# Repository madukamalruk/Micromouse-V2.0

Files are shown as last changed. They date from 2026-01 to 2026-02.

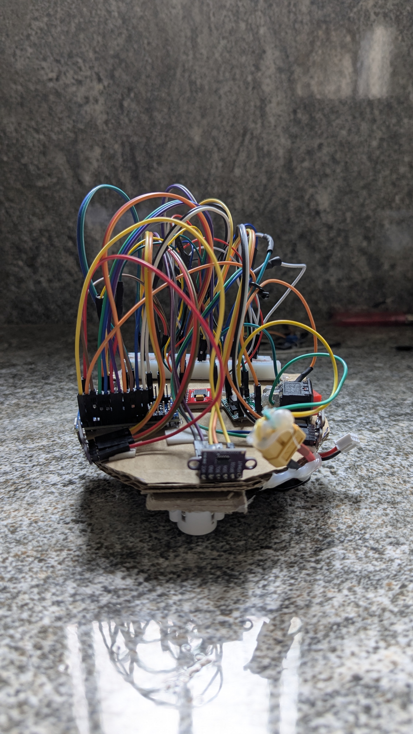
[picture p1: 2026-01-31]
IntialHardwareSetup/PXL_20260102_073045983.jpg

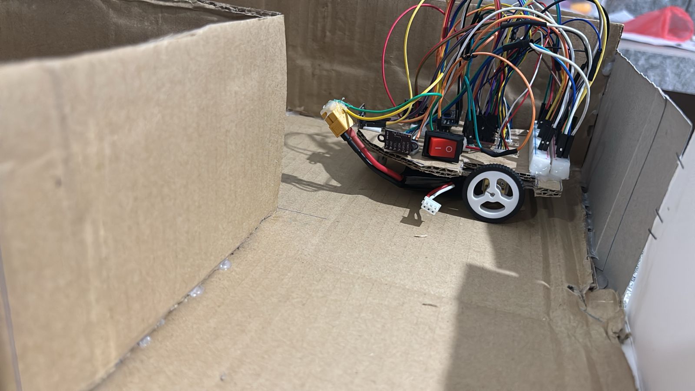
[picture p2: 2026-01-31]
IntialHardwareSetup/WhatsApp Image 2026-01-01 at 10.32.10 0PM.jpeg

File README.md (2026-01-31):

# 🐭 MazeMaster 2026 - Team MazeRiders





The official code repository for **Team MazeRiders**, a Top 5 Finalist at the **MazeMaster 2026** Micromouse competition organized by IEEE RAS Uva Wellassa University.

This project marks our transition from basic obstacle avoidance to an autonomous, intelligent maze-solving robot using the **Flood Fill Algorithm**.

---

## 🚀 Key Features

* **⚡ Autonomous Navigation:** Implements a full Flood Fill Algorithm to map and solve a 16x16 maze dynamically.
* **🧠 Two-Way Search Logic:** Features a robust "Start $\to$ Center $\to$ Start" verification run before committing the map to memory.
* **💾 Dual-Mode Operation:**
    * **Search Mode:** Explores the maze, updates wall data, and saves the verified map to EEPROM.
    * **Fast Run:** Loads the saved map and executes a high-speed run using a "Strict Visited Mask" for safety.
* **⚙️ Advanced Control System:**
    * **PID Wall Following:** Precision control using tuned $K_p$ and $K_d$ constants.
    * **Dual-Encoder Odometry:** Uses Hardware Interrupts and PCINT for precise distance tracking.
    * **Virtual Gyro:** Uses encoder differentials to maintain a straight heading in open spaces.

---

## 🛠️ Hardware Stack

| Component | Specification |
| :--- | :--- |
| **Microcontroller** | Arduino Nano (ATmega328P) |
| **Sensors** | 3x VL53L0X Time-of-Flight (ToF) Laser Sensors |
| **Motors** | N20 Gear Motors with Magnetic Encoders |
| **Driver** | TB6612FNG Dual Channel Motor Driver |
| **Power** | 2S LiPo (7.4V - 8.4V) |
| **Chassis** | Breadboard & 3D Printed Structural Components |

---

## 🏎️ How It Works

### 1. The Algorithm
The mouse treats the maze as a grid of values representing the distance to the center. We use the Flood Fill equation to update the "cost" of each cell:

$$Distance(cell) = 1 + \min(Neighbors)$$

### 2. Competition Strategy
1.  **Search Run:** The robot starts at (0,0), finds the center, and immediately drives back to the start to verify the path. The verified map is saved to non-volatile memory (**EEPROM**).
2.  **Fast Run:** The user flips a hardware switch. The robot loads the map and races to the center without scanning, strictly avoiding unvisited cells to prevent collisions.

---

## 📂 Project Structure

```bash
├── 📂Codes    # The final competition code 
├── 📂FinalHardware
├── 📂IntialHardwareSetup              
├── 📂Wiring+Dimensions                 
└── 📜 README.md   # Project documentation
```
## 👥 Team MazeRiders
• Maduka Malruk
• Sahas Wickramasinghe
• Sasidu Madhusankha

## 🏆 Achievements
• 4th Place - Round 1 (MazeMaster 2026)
• Top 4 Finalist - Final Round (MazeMaster 2026)
• Successfully implemented Flood Fill logic with custom PID tuning on an 8-bit microcontroller.

## 🤝 Acknowledgments
Special thanks to the IEEE RAS UWU Student Branch for organizing the event and the Micromouse community for the open-source knowledge that helped us migrate from Right-Hand Rule logic to Flood Fill.

### ⭐ Star this repo if you find our journey inspiring!

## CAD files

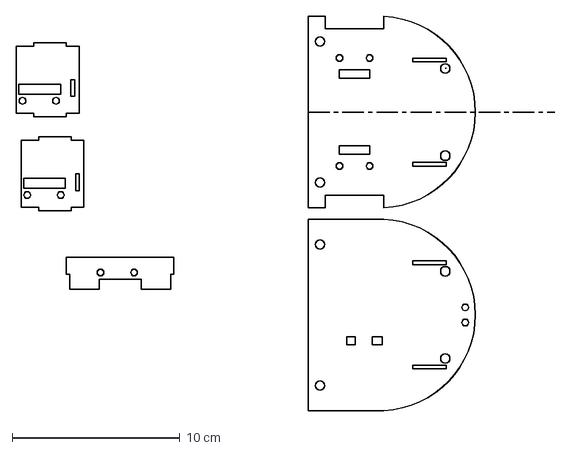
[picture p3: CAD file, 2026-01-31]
IntialHardwareSetup/board 3.DXF
32.1 x 23.5 cm

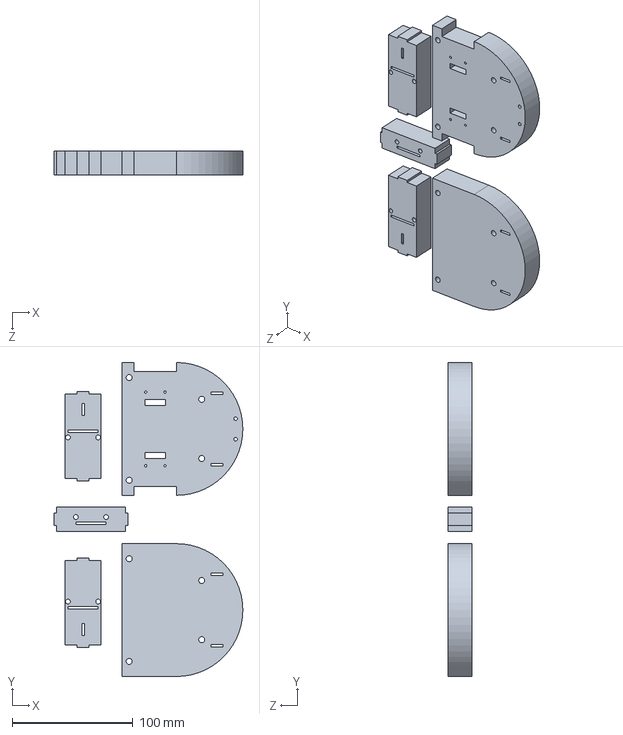
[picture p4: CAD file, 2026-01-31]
IntialHardwareSetup/board.SLDPRT
156.3 x 260.0 x 20.0 mm

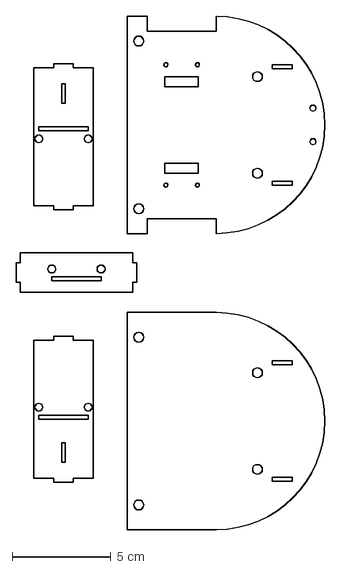
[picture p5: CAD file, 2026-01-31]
IntialHardwareSetup/board 1.DXF
15.6 x 26.0 cm

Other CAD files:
IntialHardwareSetup/board 2.SLDPRT
IntialHardwareSetup/Part1.SLDPRT
IntialHardwareSetup/board 2.DXF

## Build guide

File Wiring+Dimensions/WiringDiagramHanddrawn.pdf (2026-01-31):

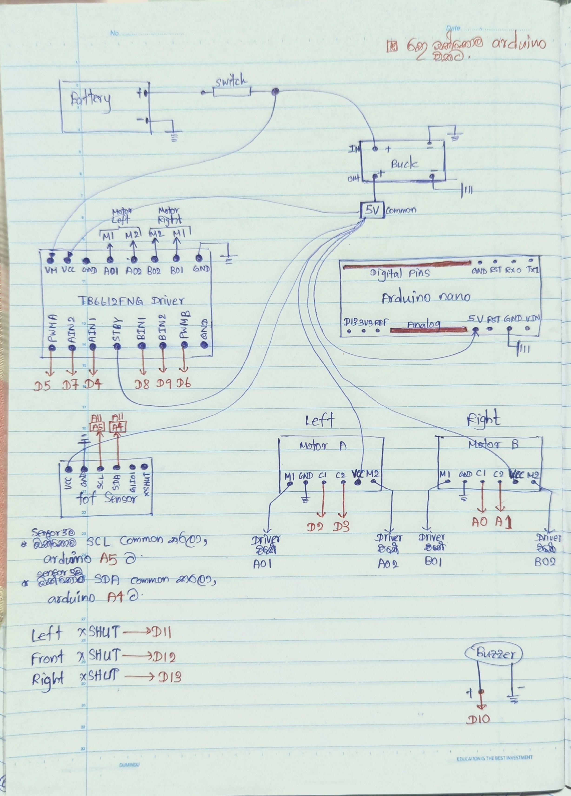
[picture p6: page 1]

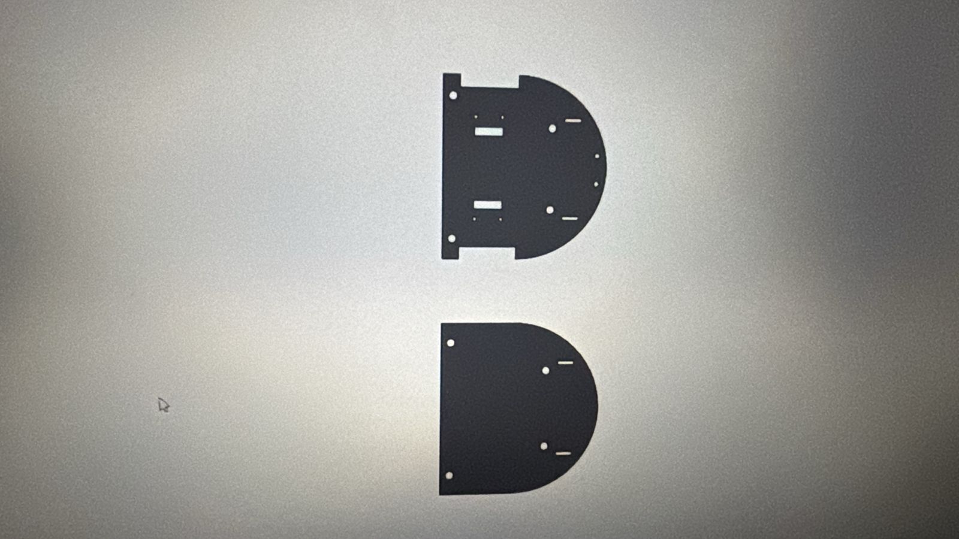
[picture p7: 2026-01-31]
IntialHardwareSetup/WhatsApp Image 2026-01-02 at 9.39.53 PM.jpeg

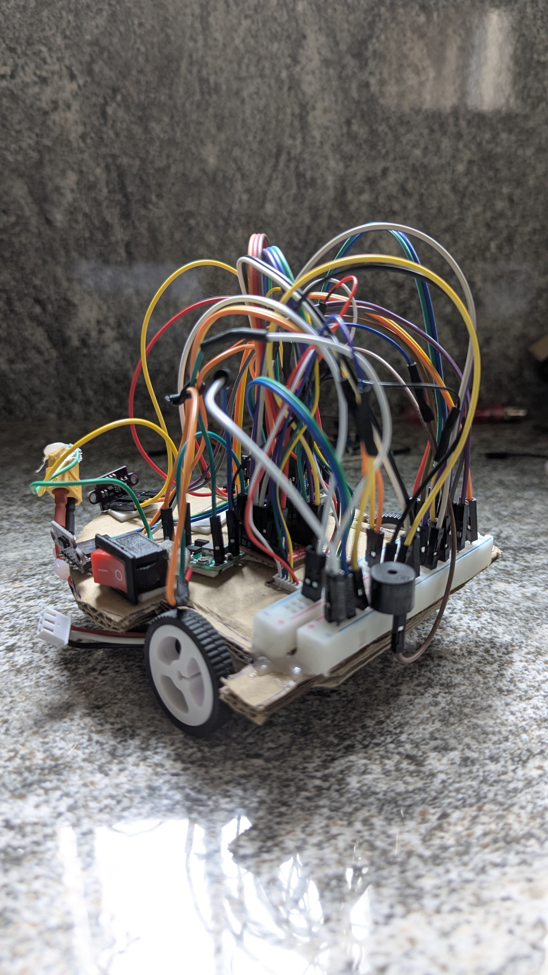
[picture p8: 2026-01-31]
IntialHardwareSetup/PXL_20260102_073117457.jpg

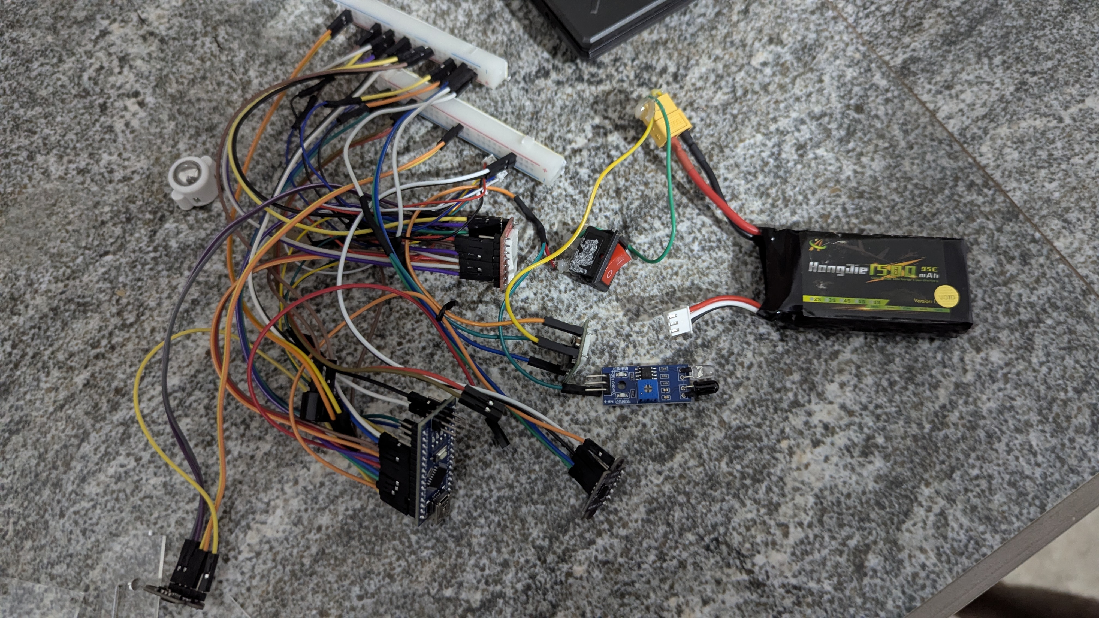
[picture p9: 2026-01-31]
IntialHardwareSetup/PXL_20260105_134254864.jpg

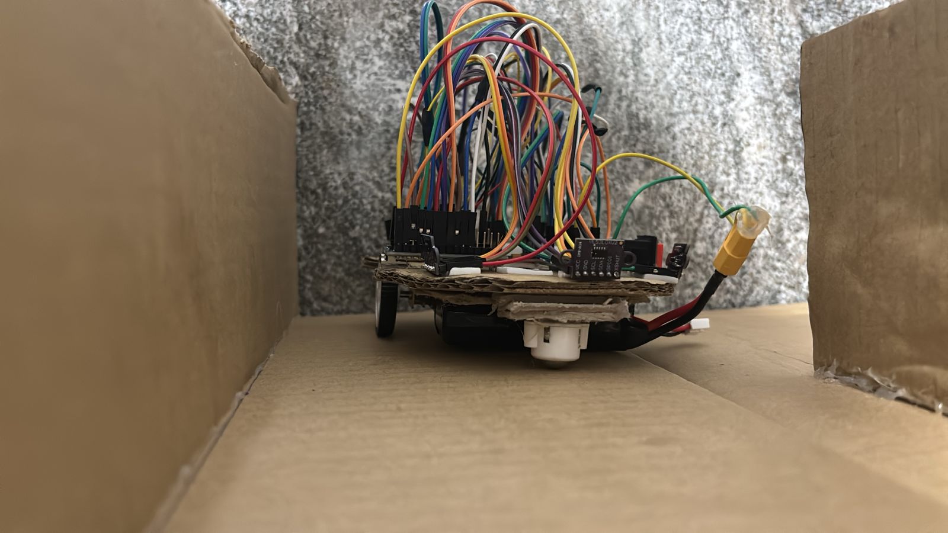
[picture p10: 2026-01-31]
IntialHardwareSetup/WhatsApp Image 2026-01-01 at 10.32.10 PM.jpeg

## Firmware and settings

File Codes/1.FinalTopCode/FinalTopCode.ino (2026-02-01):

#include <Wire.h>
#include <VL53L0X.h>
#include <EEPROM.h>

// *** TUNING MODE SELECTOR ***
// 0 = COMPETITION MODE (Standard Operation)
// 1 = TUNE DISTANCE (Moves 3 cells forward then stops)
// 2 = TUNE 90 TURN (Turns 90 degrees 4 times)
// 3 = TUNE 180 TURN (Turns 180 degrees 2 times)
const int TUNING_MODE = 2; 

// *** PHYSICAL CONSTANTS  ***
int TICKS_PER_CELL = 585;  
int TICKS_FOR_90   = 280;  
int TICKS_FOR_180  = 575; // Tune this using Mode 3!

// *** PID CONTROL ***
float Kp_Wall = 2.0;            
float Kd_Wall = 0.5;            
float Kp_Enc  = 1.0; 

// *** SPEED SETTINGS ***
int SEARCH_SPEED = 90;
int FAST_SPEED   = 100; 
int CURRENT_SPEED = 90; 
int WALL_DIST    = 75; 

// ================================================================
//               HARDWARE PIN DEFINITIONS
// ================================================================
const int AIN1 = 4; const int AIN2 = 7; const int PWMA = 5;
const int BIN1 = 9; const int BIN2 = 8; const int PWMB = 6;
const int ENCL_A = 2; const int ENCR_A = A0; 
const int buzzer = 10;
const int MODE_SWITCH_PIN = A3; 
const int xL = 11; const int xF = 12; const int xR = 13;

VL53L0X sensorL; VL53L0X sensorF; VL53L0X sensorR;

volatile long leftTicks = 0;
volatile long rightTicks = 0;

// Mapping
const int MAZE_SIZE = 16;
byte walls[16][16];       
byte dist[16][16];
byte visited[16][16]; 

int curX = 0; int curY = 0; int heading = 0;

enum RobotMode { IDLE, SEARCH_RUN, FAST_RUN };
RobotMode currentMode = IDLE;
bool searchingReturn = false; 

// ================================================================
//               INTERRUPTS
// ================================================================
void countLeft() { leftTicks++; }
ISR(PCINT1_vect) { if (digitalRead(ENCR_A) == HIGH) rightTicks++; }
long getAvgTicks() { noInterrupts(); long l = leftTicks; long r = rightTicks; interrupts(); return (l + r) / 2; }
void resetTicks() { noInterrupts(); leftTicks = 0; rightTicks = 0; interrupts(); }

// ================================================================
//               SETUP (Updated with Mode 3)
// ================================================================
void setup() {
  Serial.begin(9600);
  Wire.begin(); 

  pinMode(AIN1, OUTPUT); pinMode(AIN2, OUTPUT); pinMode(PWMA, OUTPUT);
  pinMode(BIN1, OUTPUT); pinMode(BIN2, OUTPUT); pinMode(PWMB, OUTPUT);
  pinMode(buzzer, OUTPUT); pinMode(MODE_SWITCH_PIN, INPUT_PULLUP);

  pinMode(ENCL_A, INPUT_PULLUP); attachInterrupt(digitalPinToInterrupt(ENCL_A), countLeft, RISING);
  pinMode(ENCR_A, INPUT_PULLUP); cli(); PCICR |= (1 << PCIE1); PCMSK1 |= (1 << PCINT8); sei();

  pinMode(xL, OUTPUT); pinMode(xF, OUTPUT); pinMode(xR, OUTPUT);
  digitalWrite(xL, LOW); digitalWrite(xF, LOW); digitalWrite(xR, LOW); delay(50);
  digitalWrite(xL, HIGH); delay(10); sensorL.init(); sensorL.setAddress(0x31); sensorL.setTimeout(500);
  digitalWrite(xF, HIGH); delay(10); sensorF.init(); sensorF.setAddress(0x30); sensorF.setTimeout(500);
  digitalWrite(xR, HIGH); delay(10); sensorR.init(); sensorR.setAddress(0x32); sensorR.setTimeout(500);
  sensorL.startContinuous(); sensorF.startContinuous(); sensorR.startContinuous();

  initMaze(); 
  searchingReturn = false; 

  // ============================================================
  //            TUNING MODES
  // ============================================================
  
  if (TUNING_MODE == 1) { 
    // *** MODE 1: DISTANCE TUNE ***
    // Move 3 cells forward
    for(int i=0; i<3; i++) { moveOneCell(); delay(500); } 
    while(1); 
  }
  else if (TUNING_MODE == 2) { 
    // *** MODE 2: 90 DEGREE TURN TUNE ***
    // Square path
    for(int i=0; i<4; i++) { turnInPlace(true, TICKS_FOR_90); delay(500); } 
    while(1); 
  }
  else if (TUNING_MODE == 3) {
    // *** MODE 3: 180 DEGREE U-TURN TUNE ***
    // Perform U-Turn, Wait, Perform U-Turn (Should be back at start heading)
    for(int i=0; i<2; i++) {
        turnInPlace(true, TICKS_FOR_180); 
        delay(1000);
    }
    while(1); // Freeze
  }
  else {
    // *** COMPETITION MODE ***
    if (digitalRead(MODE_SWITCH_PIN) == LOW) {
      currentMode = SEARCH_RUN;
      CURRENT_SPEED = SEARCH_SPEED;
      tone(buzzer, 1000, 200); delay(250); tone(buzzer, 1500, 400); 
    } else {
      currentMode = FAST_RUN;
      CURRENT_SPEED = FAST_SPEED;
      for(int i=0; i<3; i++) { tone(buzzer, 2000, 100); delay(150); }
      loadMapFromEEPROM();
      updateFlood();
    }
  }
  delay(1000); 
}

// ================================================================
//               MAIN LOOP
// ================================================================
void loop() {
  if (currentMode == SEARCH_RUN) runSearchLogic();
  else if (currentMode == FAST_RUN) runFastLogic();
}

// ================================================================
//               LOGIC: SEARCH RUN (Double-Save)
// ================================================================
void runSearchLogic() {
  visited[curX][curY] = 1;

  if (sensorF.readRangeContinuousMillimeters() < 150) setWall(curX, curY, heading);
  if (sensorR.readRangeContinuousMillimeters() < 150) setWall(curX, curY, (heading + 1) % 4);
  if (sensorL.readRangeContinuousMillimeters() < 150) setWall(curX, curY, (heading + 3) % 4);
  
  updateFlood(); 

  if (dist[curX][curY] == 0) {
    brake();
    
    if (!searchingReturn) {
        // Checkpoint Save (Center)
        saveMapToEEPROM(); 
        tone(buzzer, 2000, 100); delay(100); tone(buzzer, 2000, 100); delay(500);
        searchingReturn = true;
        updateFlood(); 
        return; 
    }
    else {
        // Final Save (Start)
        saveMapToEEPROM();
        tone(buzzer, 1000, 100); delay(150); tone(buzzer, 1500, 100); delay(150); tone(buzzer, 2000, 500);
        while(1); 
    }
  }
  
  int bestDir = -1;
  int minDist = 255;
  int checkOrder[4] = {0, 1, 3, 2}; 
  
  for(int i=0; i<4; i++) {
    int dir = (heading + checkOrder[i]) % 4;
    if (!isWall(curX, curY, dir)) {
      int nx = curX, ny = curY;
      if (dir==0) ny++; else if (dir==1) nx++; else if (dir==2) ny--; else if (dir==3) nx--;
      if (nx >= 0 && nx < MAZE_SIZE && ny >= 0 && ny < MAZE_SIZE) {
         if (dist[nx][ny] < minDist) { minDist = dist[nx][ny]; bestDir = dir; }
      }
    }
  }
  executeMove(bestDir);
}

// ================================================================
//               LOGIC: FAST RUN (Strict Visited)
// ================================================================
void runFastLogic() {
  if (dist[curX][curY] == 0) {
    brake(); while(1) { tone(buzzer, 3000, 500); delay(1000); }
  }

  int bestDir = -1;
  int minDist = 255;
  int checkOrder[4] = {0, 1, 3, 2}; 
  
  for(int i=0; i<4; i++) {
    int dir = (heading + checkOrder[i]) % 4;
    if (!isWall(curX, curY, dir)) {
      int nx = curX, ny = curY;
      if (dir==0) ny++; else if (dir==1) nx++; else if (dir==2) ny--; else if (dir==3) nx--;
      if (nx >= 0 && nx < MAZE_SIZE && ny >= 0 && ny < MAZE_SIZE) {
         if (visited[nx][ny] == 1) {
             if (dist[nx][ny] < minDist) { minDist = dist[nx][ny]; bestDir = dir; }
         }
      }
    }
  }
  if (bestDir == -1) { brake(); while(1) { tone(buzzer, 500, 500); delay(500); } }
  executeMove(bestDir);
}

// ================================================================
//               MOTION & HELPERS
// ================================================================
void executeMove(int bestDir) {
  if (bestDir != -1) {
    int diff = (bestDir - heading + 4) % 4;
    if (diff == 1)      { turnInPlace(true, TICKS_FOR_90); heading = (heading + 1) % 4; }
    else if (diff == 3) { turnInPlace(false, TICKS_FOR_90); heading = (heading + 3) % 4; }
    else if (diff == 2) { turnInPlace(true, TICKS_FOR_180); heading = (heading + 2) % 4; }
    moveOneCell();
    if (heading == 0) curY++; else if (heading == 1) curX++;
    else if (heading == 2) curY--; else if (heading == 3) curX--;
  }
}

void initMaze() {
  for(int i=0; i<MAZE_SIZE; i++) { for(int j=0; j<MAZE_SIZE; j++) { walls[i][j] = 0; dist[i][j] = 255; visited[i][j] = 0; } }
}
void setWall(int bx, int by, int bdir) {
  walls[bx][by] |= (1 << bdir);
  int nx = bx, ny = by;
  if (bdir == 0) ny++; else if (bdir == 1) nx++; else if (bdir == 2) ny--; else if (bdir == 3) nx--;
  if (nx >= 0 && nx < MAZE_SIZE && ny >= 0 && ny < MAZE_SIZE) { walls[nx][ny] |= (1 << ((bdir + 2) % 4)); }
}
int isWall(int bx, int by, int bdir) { return (walls[bx][by] & (1 << bdir)); }

void updateFlood() {
  for(int i=0; i<MAZE_SIZE; i++) { for(int j=0; j<MAZE_SIZE; j++) { dist[i][j] = 255; } }
  if (!searchingReturn) { dist[7][7] = 0; dist[7][8] = 0; dist[8][7] = 0; dist[8][8] = 0; } 
  else { dist[0][0] = 0; }

  int changed = 1;
  while(changed) {
    changed = 0;
    for(int i=0; i<MAZE_SIZE; i++) { for(int j=0; j<MAZE_SIZE; j++) {
        if (dist[i][j] == 255) continue;
        int nextVal = dist[i][j] + 1;
        for(int d=0; d<4; d++) {
          if (!isWall(i, j, d)) {
            int nx = i, ny = j;
            if (d==0) ny++; else if (d==1) nx++; else if (d==2) ny--; else if (d==3) nx--;
            if (nx >= 0 && nx < MAZE_SIZE && ny >= 0 && ny < MAZE_SIZE) {
               if (currentMode == FAST_RUN && visited[nx][ny] == 0) continue;
               if (dist[nx][ny] > nextVal) { dist[nx][ny] = nextVal; changed = 1; }
            }
          }
        }
    }}
  }
}

void saveMapToEEPROM() {
  int addr = 0;
  for(int i=0; i<MAZE_SIZE; i++) { for(int j=0; j<MAZE_SIZE; j++) { EEPROM.write(addr, walls[i][j]); addr++; } }
  for(int i=0; i<MAZE_SIZE; i++) { for(int j=0; j<MAZE_SIZE; j++) { EEPROM.write(addr, visited[i][j]); addr++; } }
}
void loadMapFromEEPROM() {
  int addr = 0;
  for(int i=0; i<MAZE_SIZE; i++) { for(int j=0; j<MAZE_SIZE; j++) { walls[i][j] = EEPROM.read(addr); addr++; } }
  for(int i=0; i<MAZE_SIZE; i++) { for(int j=0; j<MAZE_SIZE; j++) { visited[i][j] = EEPROM.read(addr); addr++; } }
}

void setMotors(int leftSpeed, int rightSpeed) {
  leftSpeed = constrain(leftSpeed, -255, 255); rightSpeed = constrain(rightSpeed, -255, 255);
  if (leftSpeed >= 0) { digitalWrite(AIN1, HIGH); digitalWrite(AIN2, LOW); analogWrite(PWMA, leftSpeed); }
  else                { digitalWrite(AIN1, LOW);  digitalWrite(AIN2, HIGH); analogWrite(PWMA, -leftSpeed); }
  if (rightSpeed >= 0) { digitalWrite(BIN1, HIGH); digitalWrite(BIN2, LOW); analogWrite(PWMB, rightSpeed); }
  else                 { digitalWrite(BIN1, LOW);  digitalWrite(BIN2, HIGH); analogWrite(PWMB, -rightSpeed); }
}
void brake() {
  digitalWrite(AIN1, HIGH); digitalWrite(AIN2, HIGH); digitalWrite(BIN1, HIGH); digitalWrite(BIN2, HIGH);
  analogWrite(PWMA, 255); analogWrite(PWMB, 255); delay(100); analogWrite(PWMA, 0); analogWrite(PWMB, 0);
}
void moveOneCell() {
  resetTicks(); float previousError = 0; unsigned long lastMoveTime = millis(); long lastTicks = 0;
  while(getAvgTicks() < TICKS_PER_CELL) {
    if (millis() - lastMoveTime > 200) { if (getAvgTicks() == lastTicks) { brake(); tone(buzzer, 500, 300); setMotors(-80, -80); delay(300); brake(); return; } lastTicks = getAvgTicks(); lastMoveTime = millis(); }
    int dL = sensorL.readRangeContinuousMillimeters(); int dR = sensorR.readRangeContinuousMillimeters();
    float adjustment = 0; bool wallLeft = (dL < 150); bool wallRight = (dR < 150);
    if (wallLeft && wallRight) { float error = dL - dR; adjustment = (error * Kp_Wall) + ((error - previousError) * Kd_Wall); previousError = error; }
    else if (wallLeft) { float error = dL - WALL_DIST; adjustment = (error * Kp_Wall) + ((error - previousError) * Kd_Wall); previousError = error; }
    else if (wallRight) { float error = WALL_DIST - dR; adjustment = (error * Kp_Wall) + ((error - previousError) * Kd_Wall); previousError = error; }
    else { noInterrupts(); long errEnc = leftTicks - rightTicks; interrupts(); adjustment = errEnc * Kp_Enc; }
    setMotors(CURRENT_SPEED - adjustment, CURRENT_SPEED + adjustment);
  }
  brake();
}
void turnInPlace(bool right, int ticks) {
  resetTicks();
  while (getAvgTicks() < ticks) { if (right) setMotors(CURRENT_SPEED, -CURRENT_SPEED); else setMotors(-CURRENT_SPEED, CURRENT_SPEED); }
  brake();
}

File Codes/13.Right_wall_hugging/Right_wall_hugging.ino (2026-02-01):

#include <Wire.h>
#include <VL53L0X.h>

// ================================================================
//                      PIN DEFINITIONS
// ================================================================
const int AIN1 = 4; const int AIN2 = 7; const int PWMA = 5; 
const int BIN1 = 9; const int BIN2 = 8; const int PWMB = 6; 
const int ENCL_A = 2; const int buzzer = 10;
const int xL = 11; const int xF = 12; const int xR = 13; 

VL53L0X sensorL; VL53L0X sensorF; VL53L0X sensorR;
volatile long leftTicks = 0;

// ================================================================
//                 TUNING PARAMETERS
// ================================================================
float Kp = 2.0;            // Steering strength
float Kd = 0.5;            // Stability (lowered slightly for smoother turns)
int BASE_SPEED = 70;       // Slower speed for better decisions
int MAX_SPEED = 90;       
int WALL_DIST = 70;        // Target distance from side wall
int FRONT_STOP_DIST = 80; // Stop distance for front wall
int TICKS_FOR_90 = 292;    // YOUR TURN CALIBRATION
int TICKS_FOR_180 = 609;   // Approx double 90 turn

float previousError = 0;

void countTicks() { leftTicks++; }

// ================================================================
//                      SETUP
// ================================================================
void setup() {
  Serial.begin(9600);
  Wire.begin();
  
  pinMode(AIN1, OUTPUT); pinMode(AIN2, OUTPUT); pinMode(PWMA, OUTPUT);
  pinMode(BIN1, OUTPUT); pinMode(BIN2, OUTPUT); pinMode(PWMB, OUTPUT);
  pinMode(ENCL_A, INPUT_PULLUP);
  attachInterrupt(digitalPinToInterrupt(ENCL_A), countTicks, RISING);
  
  pinMode(xL, OUTPUT); pinMode(xF, OUTPUT); pinMode(xR, OUTPUT);
  digitalWrite(xL, LOW); digitalWrite(xF, LOW); digitalWrite(xR, LOW);
  delay(50);
  
  digitalWrite(xL, HIGH); delay(10); sensorL.init(); sensorL.setAddress(0x31); sensorL.setTimeout(500);
  digitalWrite(xF, HIGH); delay(10); sensorF.init(); sensorF.setAddress(0x30); sensorF.setTimeout(500);
  digitalWrite(xR, HIGH); delay(10); sensorR.init(); sensorR.setAddress(0x32); sensorR.setTimeout(500);
  
  sensorL.startContinuous(); sensorF.startContinuous(); sensorR.startContinuous();
  
  tone(buzzer, 2000, 100); delay(1000); // Quick start
}

// ================================================================
//                      MOTOR CONTROL
// ================================================================
void setMotors(int leftSpeed, int rightSpeed) {
  leftSpeed = constrain(leftSpeed, -MAX_SPEED, MAX_SPEED);
  rightSpeed = constrain(rightSpeed, -MAX_SPEED, MAX_SPEED);

  if (leftSpeed >= 0) { digitalWrite(AIN1, HIGH); digitalWrite(AIN2, LOW); analogWrite(PWMA, leftSpeed); }
  else                { digitalWrite(AIN1, LOW); digitalWrite(AIN2, HIGH); analogWrite(PWMA, -leftSpeed); }
  
  if (rightSpeed >= 0) { digitalWrite(BIN1, HIGH); digitalWrite(BIN2, LOW); analogWrite(PWMB, rightSpeed); }
  else                 { digitalWrite(BIN1, LOW); digitalWrite(BIN2, HIGH); analogWrite(PWMB, -rightSpeed); }
}

void brake() {
  digitalWrite(AIN1, HIGH); digitalWrite(AIN2, HIGH);
  digitalWrite(BIN1, HIGH); digitalWrite(BIN2, HIGH);
  analogWrite(PWMA, 255); analogWrite(PWMB, 255);
  delay(150);
  analogWrite(PWMA, 0); analogWrite(PWMB, 0);
}

// --- TURN FUNCTIONS ---
void turn(bool right, int ticks) {
  leftTicks = 0;
  while (leftTicks < ticks) {
    if (right) setMotors(100, -100); // Spin Right
    else       setMotors(-100, 100); // Spin Left
  }
  brake();
  previousError = 0; // Reset PID
  delay(200);        // Wait for sensors to settle
}

// ================================================================
//                 SMART INTERSECTION LOGIC
// ================================================================
void handleIntersection() {
  brake(); // STOP! Wall ahead.
  
  int dL = sensorL.readRangeContinuousMillimeters();
  int dR = sensorR.readRangeContinuousMillimeters();
  
  Serial.print("DECISION -> L:"); Serial.print(dL); Serial.print(" R:"); Serial.println(dR);

  // LOGIC: Check where the open space is (> 200mm)
  
  // 1. If Left is Open, Turn Left
  if (dL > 200) {
    Serial.println("Turning LEFT");
    turn(false, TICKS_FOR_90);
  }
  // 2. If Right is Open, Turn Right
  else if (dR > 200) {
    Serial.println("Turning RIGHT");
    turn(true, TICKS_FOR_90);
  }
  // 3. Dead End (Both sides blocked)
  else {
    Serial.println("DEAD END");
    turn(true, TICKS_FOR_180); // Spin 180
  }
}

// ================================================================
//                    MAIN LOOP (PID + LOGIC)
// ================================================================
void loop() {
  int dL = sensorL.readRangeContinuousMillimeters();
  int dR = sensorR.readRangeContinuousMillimeters();
  int dF = sensorF.readRangeContinuousMillimeters();

  // 1. SAFETY: Stop at Front Wall
  if (dF < FRONT_STOP_DIST && dF > 5) {
    handleIntersection(); // Call the brain!
    return; // Restart loop after turning
  }

  // 2. PID CALCULATION (Keep Going Straight)
  float error = 0;

  // Priority: If we have a Right wall, hug it 
  if (dR < 150) {
    error = WALL_DIST - dR; // Hug Right
  }
  // If no Right wall but Left wall exists, hug Left
  else if (dL < 150) {
    error = dL - WALL_DIST; // Hug Left
  }
  // If in corridor (both walls), center yourself
  else if (dL < 150 && dR < 150) {
    error = dL - dR; 
  }
  
  // 3. APPLY PID
  float P = error * Kp;
  float D = (error - previousError) * Kd;
  float adjustment = P + D;
  previousError = error;

  // Steering Logic:
  // Positive Adj -> Turn Left (Right motor faster)
  // Negative Adj -> Turn Right (Left motor faster)
  int leftMotorSpeed  = BASE_SPEED - adjustment;
  int rightMotorSpeed = BASE_SPEED + adjustment;

  setMotors(leftMotorSpeed, rightMotorSpeed);
}

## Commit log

2026-01-31 commiting my local project folder of mazesolver robot
    [Part1.SLDPRT, board 1.DXF, board 2.DXF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]
2026-02-01 Update motor pin definitions and constants
2026-02-01 Clean up comments and retain pin definitions
    Removed comments related to previous sensor setup and emergency brake feature.
2026-02-01 Update pin definitions and comments in motor_rotating.ino
